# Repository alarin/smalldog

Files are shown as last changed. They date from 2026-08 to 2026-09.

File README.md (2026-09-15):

# SmallDog

A 12-DOF printed quadruped ("mini robot dog") built around 12 × Feetech/Waveshare
**ST3215** bus servos — parametric CAD, FEA, a ROS 2 / MuJoCo simulation, an RL policy and
the hardware runtime, all of one robot.

| | |
|---|---|
| [`3d/`](3d/) | **the source of truth.** Pure code-CAD (CadQuery): every dimension, mass and joint limit lives in [`3d/mini_dog.py`](3d/mini_dog.py). Also linear-static FEA ([`fea.py`](3d/fea.py)) and the URDF/MJCF exporter ([`export_sim.py`](3d/export_sim.py)). |
| [`ros2/`](ros2/) | ROS 2 workspace: generated description, `ros2_control` wiring, trot gait, teleop, SLAM + Nav2 + room exploration, MuJoCo standing in for the hardware. |
| [`rl/`](rl/) | the RL walking policy: MJX/Brax PPO against the same generated model. |
| [`robot/`](robot/) | the hardware side: ST3215 bus driver, the identification bench, the 50 Hz runtime. |

Everything structural is FDM-printed (PETG/ASA): no aluminium, no machining, no external
bearings — only the stock servos and their aluminium hubs.

## One model, three consumers

`ros2/smalldog_description` is **generated**, not authored:

```bash
cd ros2 && ../3d/.venv/bin/python smalldog_description/scripts/generate_model.py
```

Masses, inertias, link lengths, joint limits, the actuator constants and the sensor
parameters are all read out of `3d/mini_dog.py`. A number that is wrong in simulation is
wrong in the CAD — fix it there and re-export. [`3d/CLAUDE.md`](3d/CLAUDE.md) has the
change workflow (rebuild → FEA → re-export sim → regenerate the ROS 2 description).

## Machines

| machine | does | runbook |
|---|---|---|
| a mac | CAD, FEA, both sim exporters, the ROS 2 workspace | [`3d/CLAUDE.md`](3d/CLAUDE.md) |
| Windows/WSL2, RTX 3070 | RL training, the pure-Python sim regressions | [`WSL.md`](WSL.md) |
| Windows/WSL2, RTX 5070 Ti | RL training with the procedural boxes at full batch | [`GPU.md`](GPU.md) |
| Orange Pi 5 Pro | the runtime on the robot | [`robot/README.md`](robot/README.md) |

No shared filesystem between them: the git repository is the only thing that crosses.

## Where to read

- Printed parts, servo interface, assembly: [`3d/README.md`](3d/README.md)
- Simulation, gait, teleop, SLAM and navigation, regressions: [`ros2/README.md`](ros2/README.md)
- Bench, bring-up, the measured servo: [`robot/README.md`](robot/README.md) and the public
  reference [`ST3215_STS3215_measured_parameters.md`](ST3215_STS3215_measured_parameters.md)
- Power tree and its **verify** list: [`POWER.md`](POWER.md)
- What to build next: [`PLAN.md`](PLAN.md)

## Not in this repository

Generated output is ignored — `3d/out/` (STEP/STL/BOM/renders/FEA meshes), `rl/runs/`
(checkpoints) and the colcon `build/`, `install/`, `log/` trees. Re-run the scripts to
produce them.

`3d/ref/` holds vendor downloads (ST3215 STEP + drawings, Waveshare ROBOTIC DOG STEP) and
transcribed measurements of bought parts, used as inputs only; they remain the property of
their respective vendors.

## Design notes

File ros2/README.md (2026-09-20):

# SmallDog — ROS 2 + MuJoCo

12-DOF quadruped simulation for the printed ST3215 dog designed in [`../3d`](../3d):
description → ros2_control → gait node, with MuJoCo standing in for the hardware.

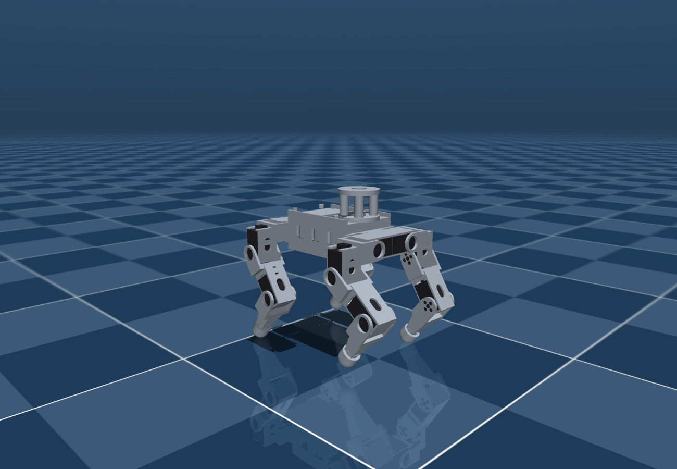
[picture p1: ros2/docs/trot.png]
trot


## Packages

| Package | Type | Purpose |
|---|---|---|
| `smalldog_description` | ament_cmake | URDF, link meshes, MuJoCo model — **all generated from the CAD** |
| `smalldog_ros_control` | ament_cmake | ros2_control wiring + MuJoCo launch |
| `smalldog_walker` | ament_python | trot gait + analytic leg IK, `/cmd_vel` → joint trajectory |
| `smalldog_teleop` | ament_python | keyboard teleop |
| `smalldog_hardware` | ament_python | **the real robot**: `robot/runtime`'s servo loop behind the walker's topics, the L2 and the camera as topics, `/diagnostics` and a Foxglove bridge — "On the robot" below |
| `smalldog_nav` | ament_python | SLAM + Nav2 + the frontier explorer: the robot maps a room by itself — "SLAM and navigation" below |
| `tools/` | — | standalone MuJoCo sim, no ROS needed |

One external source dependency: **`mujoco_ros2_control`**, a fork on its `kilted` branch,
vendored as a submodule at `src/mujoco_ros2_control`. The LiDAR publisher, the camera
checks and the real-time pacing live there, so a pull that touches them needs one
`colcon build --packages-select mujoco_ros2_control`.

## Build & run

The workspace has its own ROS 2 environment in `pixi/` (macOS arm64 only, as committed).

```bash
pixi install --manifest-path ros2/pixi/pixi.toml    # ~2.3 GB, once
git submodule update --init                        # src/mujoco_ros2_control
source tools/env.sh
colcon build --symlink-install
```

Four pins in `pixi/pixi.toml` are load-bearing: `ros2_control 5.6` / `ros2_controllers 5.7`
(by hardware_interface 5.12 the fork's `MujocoSystemInterface` matches no `import_component`
overload); `libmujoco 3.3` (`mjv_moveCamera` grew an argument after); `clang_osx-arm64` by
name (without the conda wrapper's `-dead_strip_dylibs` the node links 18 rosidl dylibs it
never calls and dies at startup on `_PyExc_RuntimeError`); and `filelock`, which the
controller spawner imports.

One controller parameter is load-bearing too: `interpolate_from_desired_state: true` on
the trajectory controller (`config/smalldog-controllers.yaml`). ros2_controllers 5.7
renamed `open_loop_control` to it and dropped the old key without a word, and with it off
every streamed point restarts the interpolation from where the lagging servo actually is:
the trot reached the joints at ~40 % of its amplitude, and a 0.5 rad/s turn came out at
0.026 rad/s against 0.30 in the standalone sim (0.27 with the key). The walker also
clocks the gait on measured elapsed time now, not the timer's nominal period — a loaded
mac fires its 100 Hz timer at 65.

### Run

One terminal. Keys are read by the **MuJoCo render window** — the sim node republishes
every printable key on `~/key`, and the teleop node turns them into `/cmd_vel`. Click the
window and type.

```bash
./tools/sim.sh                 # flat ground, real time
./tools/sim.sh terrain:=true   # the heightfield scene
./tools/sim.sh teleop:=false   # no teleop node — drive it from a second terminal
./tools/sim.sh foxglove:=true  # plus a Foxglove websocket on ws://localhost:8765
./tools/sim.sh rtf:=2.0        # twice real time; rtf:=0 is unpaced (long unattended runs)
```

`sim.sh` kills stray `robot_state_publisher` processes first: a leftover keeps the next
`controller_manager` from coming up (`waiting for service /controller_manager/list_controllers`
forever). `tools/teleop.sh` is the second-terminal path for a headless or remote run; launch
with `teleop:=false` when you use it, or two teleop nodes fight over `/cmd_vel`.

```bash
pkill -f "ros2 launch smalldog"; pkill -f robot_state_publisher    # stopping
```

`tools/env.sh` picks `local_setup.zsh` or `.bash` to match the shell: sourcing the `.bash`
file from zsh silently never applies the overlay (`$BASH_SOURCE` is unset), and
`ros2 run smalldog_teleop keyboard` then says "package not found".

By hand:

```bash
eval "$(pixi shell-hook --manifest-path pixi/pixi.toml)"
source install/local_setup.bash
ros2 launch smalldog_ros_control smalldog-mujoco.launch.py
ros2 run smalldog_teleop keyboard                            # second terminal
```

### Checking it is alive

```bash
ros2 control list_controllers        # both must say "active"
ros2 node list | grep smalldog       # walker, controller, keyboard_teleop
ros2 topic info /cmd_vel             # 1 publisher (teleop), 1 subscriber (walker)
ros2 topic echo /mujoco_ros2_control_node/key   # what the render window is seeing
```

If the legs do not move: the teleop prints the `vx / vy / wz` it sends on every key. Silent
key topic → the MuJoCo window has no focus. Keys but no `/cmd_vel` → the teleop node is not
up. `/cmd_vel` with **2 publishers** → a leftover teleop still holding a command.

## Keyboard

```
  w / s      walk forward / back
  a / d      strafe left / right
  q / e      turn left / right
  space      stop
  r / f      body up / down          (0.09 … 0.20 m)
  , / .      speed  -  / +           (0.05 … 0.45 m/s)
  t          gait enable / disable
```

Published: `/cmd_vel` (Twist), `/smalldog/body_height` (Float64), `/smalldog/enable` (Bool).
Subscribed: `/mujoco_ros2_control_node/key` (String, one character per press). Backspace
belongs to the viewer and resets the sim. `read_stdin:=false` turns the raw-TTY reader off;
the node does that by itself whenever stdin is not a TTY.

## Without ROS 2

The gait and IK have no ROS imports, so everything runs from a bare env with `mujoco` and
`numpy`:

```bash
./tools/view.sh                             # interactive viewer, same key bindings
./tools/view.sh --terrain --lidar           # rough ground, with the LiDAR cloud drawn
python tools/standalone_sim.py --headless   # self-test: stand, trot, turn
python tools/standalone_sim.py --terrain    # either mode, on the rough-ground scene
python tools/standalone_sim.py --course     # 25 s over the ramp/wall/log obstacle course
python tools/standalone_sim.py --lidar      # ... with the L2 scanning (needs ../3d beside)
```

The interactive viewer goes through `tools/view.sh`: on macOS the passive viewer needs
`mjpython`, which cannot dlopen the uv venv's interpreter, and the wrapper sets
`DYLD_FALLBACK_LIBRARY_PATH` from `sysconfig`.

**Both viewers are paced to real time** (measured 1.000× off `/clock`; `rtf:=` on the ROS
launch, `CATCHUP` in `interactive()`). Unpaced they ran 1.5–3× real time, which is exactly
the kind of thing you calibrate your eye against. A machine that cannot keep up degrades
to slow motion rather than sprinting through a backlog. The headless runs are deliberately
not paced. Rendering is ~70 % of a frame and physics plus the whole ros2_control stack 7 %;
nothing there is worth optimising.

Current self-test:

```
model ok: 18 dof, 12 actuators, mass 2.493 kg
  stand    z= 170.6 mm  roll= +0.0 pitch= +0.1
  hold 1s  z= 170.5 mm  roll= +0.0 pitch= +0.0  drift= 21.0 mm
  trot 5s  z= 169.9 mm  roll= +2.8 pitch= -1.1  travelled x= 457.9 mm  y= -10.6 mm
  turn 4s  z= 152.9 mm  roll= +1.5 pitch= +1.4
RESULT: OK — stands and trots forward
```

`settle()` seeds the gait's rate limiter from the stance (it used to take one command at
`dt = 0`, which the limiter turned into 3e-4 rad, so the robot "settled" with straight legs
and every trot started from a ramp). The flat trot is deterministic to 0.1 mm and is the
control for any change; the terrain and course arms are read over seeds. `3d/CLAUDE.md`
carries the current baseline and how to read it.

## Rough ground

`mujoco/scene_terrain.xml` is the same world with the plane swapped for a heightfield —
`meshes/terrain.png`, generated by `../3d/terrain.py` and rewritten by `generate_model.py`.
Seeded fractal noise, ±27 mm over 160 mm (36° peak slope), flat inside 160 mm of the origin.
Same seed, same ground.

```bash
python tools/standalone_sim.py --headless --terrain            # default seed
python tools/standalone_sim.py --headless --terrain --blind    # feedback off
```

**One seed is not a measurement.** At fixed settings the trot spreads ±70 mm across seeds
and one seed moves ±100 mm under mass changes far too small to be a geometry regression.
Sweep seeds 7…12, one png per seed — MuJoCo caches a heightfield by file name inside a
process, so rewriting `terrain.png` and reloading silently reuses the first field compiled.
A dead-flat heightfield already costs the blind gait ~15 % against `type="plane"` (that is
the hfield contact, not the relief), so raising the amplitude is not the knob it looks like.

Terrain feedback against `--blind`, twelve seeds: better on 10 of 12; the blind trot rolls
over on two seeds and the closed loop never exceeds 13° of tilt. It costs ~4 % on the flat.

### The obstacle course

The heightfield alone is smooth — a foot always lands on a hillside. The scene also
carries ramps, walls and logs (`COURSE` in `../3d/terrain.py`) along +x, graded to what the
trot can clear (measured one obstacle at a time: ramps to 14°, walls to ~18 mm, logs to
~22 mm — the wall cliff between 18 and 22 mm is the 22 mm foot swing exactly). It starts at
x = 0.95 m, past what the 5 s regression trot reaches, so `--headless --terrain` measures
the relief and nothing else. `--course` walks it:

```
course: log at 950, ramp_up at 1583, deck at 1875, ramp_dn at 2166, wall at 2600, ...
  cleared 2/7: log ramp_up
  furthest x while inside the course corridor: 1791 mm
RESULT: upright ...
```

An obstacle is credited only when the robot passed it while still inside the 0.80 m
corridor — scoring on x alone credits walking around things. It is a *report*, not a
pass/fail: the unchanged model reads 5/7, 4/7 and 3/7 across sessions on one seed, and
seed 7 sits on a knife edge at the first obstacle. Read it over seeds 7 / 8 / 9.

An obstacle's rotation is a **quaternion**: `robot.xml` compiles with `angle="radian"`, so
a degree value is read as radians without a word. Ray-cast the *compiled* scene to check.
`generate_model.py --no-terrain-obstacles` leaves the course out;
`--terrain-amp/--terrain-wave/--terrain-seed` regenerate the field (restart the sim — it
keeps the heightfield it loaded).

### Terrain feedback

`smalldog_walker/gait.py` closes three loops on top of the open-loop profile, all fed by
`TrotGait.feedback(quat=..., gyro=..., contact=...)`:

- **body levelling** on the IMU: a body rotation lifts the foot corner at (x, y) by
  `roll·y − pitch·x` and the leg retracts by the same amount. Acts on the attitude
  low-passed over 0.30 s — most of what the IMU sees is the trot's own rocking, and chasing
  that costs half the forward speed.
- **stand where you land**: a debounced contact partway through the swing means the ground
  came up; the foot stops there instead of finishing a sine that would peel it off.
- **heading hold** on the IMU yaw. The command is in body axes, so a robot knocked off
  course curves through the world and the profile cannot notice. The reference is latched
  when it last started walking straight and dropped on a commanded turn.

Hold off → on over six terrain seeds: on the flat nothing changes; on the relief the final
|yaw| goes 9.4° → 3.9°; on the course 46.6° → 10.3°, path 2292 → 2836 mm, 1/6 → 0/6 down,
and the default seed goes from 1 obstacle cleared to 5. The loop corrects heading, not
position. **Sim yaw is truth; hardware yaw is an integrated gyro** (no magnetometer) — it
holds a line over a run, not an absolute bearing.

All three are optional and additive: with neither stream arriving, or either stale for
0.20 s, the gait is the blind gait. Under the ROS 2 launch the IMU arrives
(`imu_sensor_broadcaster`; the walker logs `IMU is live`); the foot contacts have no
publisher (Known gaps). Contact thresholds are keyed to the *measured* phase lag — the foot
leaves at s ≈ 0.6 and lands at ≈ 0.05, a tenth of a cycle behind the profile — and that lag
is the gait's own rate limiter, not the servo, so it wants re-measuring on hardware.

## LiDAR

The Unitree L2 is in the model as a **sensor**: `mujoco/robot.xml` carries a `lidar` site at
its optical centre and a `<custom>` block with the scan parameters, both written by
`../3d/lidar.py` out of the CAD.

```
/mujoco_ros2_control_node/lidar/points   sensor_msgs/PointCloud2, 12 Hz, SensorDataQoS
```

~5195 points a frame (measured 62340 /s at 12 Hz), float32 xyz in `lidar_link`, whose +Z is
the sensor's own axis, pointing forward (`LIDAR_TILT` 90). Simulated time stamps. About a quarter of the
rays return: the ground from ~280 mm ahead outwards, the course, and the robot's own legs
(the chassis it is bolted to is excluded; the legs are not, because a real sensor sees
them). The publisher is `src/mujoco_ros2_control/.../mujoco_lidar.{hpp,cpp}`; it uses
`mj_multiRay` with no GL context, runs at the sim cadence, and stays quiet on a model with no
`lidar` site. The scan *pattern* (measured, `3d/ref/lidar/`) exists twice — Python and C++ — because neither can
call the other; the parameters exist once, in the CAD. `smalldog_nav` is what subscribes
to the cloud.

**GPS**: mass and a frame only — 25 g on the mast, a `gps` site at the patch's phase centre
and a `gps_link` on TF (+Z the patch normal). No simulated fix; on hardware it is an NMEA
stream on a UART, not a ROS 2 sensor this workspace owns.

### Looking at it

```bash
./tools/view.sh --terrain --lidar              # MuJoCo's own viewer, cloud drawn into the scene
./tools/sim.sh terrain:=true foxglove:=true    # ROS 2 topic → ws://localhost:8765
```

The viewer draws the last six frames (0.6 s) in world coordinates, coloured by height,
subsampled to `CLOUD_MAX` = 6000 spheres. For the ROS 2 topic use **Foxglove, not RViz**
(`rviz2` is not in the pixi env and is not going in): *Open connection* → *Foxglove
WebSocket* → `ws://localhost:8765`, a 3D panel, the `…/lidar/points` topic, frame
`base_link`. The bridge advertises `/tf`, `/tf_static` and `/robot_description` with the
`assets` capability, so the URDF and its meshes load. It binds `127.0.0.1`; change `address`
in the launch file to watch from another machine. QoS matches the publisher's automatically.
The MuJoCo window the ROS launch opens does **not** show the cloud.

```bash
ros2 topic hz /mujoco_ros2_control_node/lidar/points
ros2 bag record -s mcap /mujoco_ros2_control_node/lidar/points /tf /tf_static /clock
```

Foxglove opens an `.mcap` directly, which is how to look at a run from another machine.

## SLAM and navigation

`smalldog_nav` maps a room with the L2 and walks it by itself. One command in the sim:

```bash
./tools/explore.sh                          # MuJoCo in the walled room + SLAM + Nav2 + explorer
./tools/explore.sh rtf:=2.0 save_map:=/tmp/room
```

Watch it on Foxglove (`ws://localhost:8765`, a 3D panel, frame `map`): `/map`, `/scan`,
`/global_costmap/costmap`, `/plan`. The MuJoCo window shows the robot; keys typed over it
do nothing here (`teleop:=false`, Nav2 owns `/cmd_vel`).

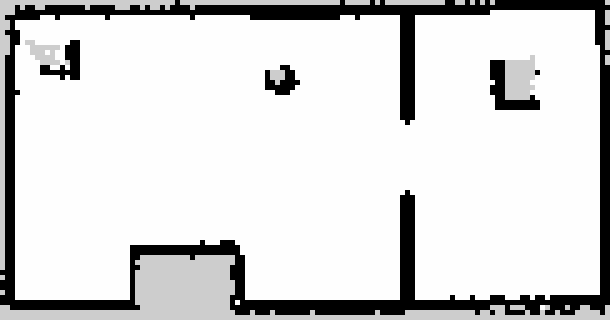
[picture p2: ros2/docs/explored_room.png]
the room, explored


What one run reads (2026-09-15, real time, the mac in a video call beside it): a 25 s spin
on the spot, then ten goals in 4.5 min, one blacklisted, and `explored: no frontier left.
17.8 m2 known, 15.2 m2 free` — the two rooms are 18 m² of floor. The map above is that
run's `save_map` output: both rooms, the doorway, the pillar, the couch and both crates,
walls one cell thick. Most goals end as "is mapped, moving on" rather than "reached": a
frontier is the edge of what the L2 has seen, and on a 6 m sensor in a 6 m world the edge
moves before the robot gets there — that is the exploration working, not failing.

The chain, each step one node:

| step | node | in → out |
|---|---|---|
| odometry | `smalldog_walker` (in the walker, `odom:=true` default) | gait velocity + IMU yaw → `/odom`, TF `odom → base_footprint → base_link` |
| cloud → scan | `smalldog_nav cloud_to_scan` | the L2 cloud → `/scan`, a 0.10..0.35 m slice in the level frame, ±96°, plus every drop in the floor as a wall at its edge |
| SLAM | `slam_toolbox` (async, mapping) | `/scan` + `odom` → `/map`, TF `map → odom` |
| navigation | Nav2: planner (NavFn), controller (regulated pure pursuit), behaviors, BT | `/map`, `/scan`, a goal → `/cmd_vel` |
| exploration | `smalldog_nav explore` | `/map` → `navigate_to_pose` goals until no frontier is left |

`nav.launch.py` is the chain without the sim, for either machine:

```bash
ros2 launch smalldog_nav nav.launch.py explore:=true                 # sim (sim.sh teleop:=false first)
ros2 launch smalldog_nav nav.launch.py use_sim_time:=false cloud:=/lidar/points speed:=0.12 explore:=true
                                                                     # robot (robot.launch.py imu:=true lidar:=true)
ros2 topic pub -1 /smalldog/explore std_msgs/msg/Bool "{data: false}"   # pause; true resumes
```

**With the gamepad** the two take turns on `/cmd_vel` instead of fighting: launch with
`explore:=true autostart:=false`, and **Back** hands the robot to Nav2 (the pad goes
silent — no zeros either); any stick push or B takes it back and pauses the explorer;
Back again resumes. When the explorer finishes it hands the pad back on its own.

**Odometry** is dead reckoning: the walker integrates the velocity its stance feet are
sweeping (the command after the heading hold and the stride clamps, `TrotGait.body_velocity()`)
times `odom_scale`, and takes heading from the IMU (truth in the sim, an integrated gyro on the
robot). `odom_scale` is the foot slip: the sim trot delivers ~0.5 of its command on the flat
(measured against `qpos` over 6 s: 0.53 at 0.15 m/s, 0.49 at 0.10, 0.67 at period 1.35), so
the sim launch sets 0.5; the robot's is unmeasured (**verify** — walk a taped 2 m and compare
`/odom`). slam_toolbox's scan matcher absorbs the rest; a scan node every 0.1 m keeps its
0.5 m search window honest. `base_footprint` is the level frame: base_link lifted by the
standing height and tilted back by the IMU's roll and pitch, so the scan slice keeps the
floor out while the trot rocks the body ±3°.

**The scan** is ±96° — the L2's cone about its forward axis — and no wider: behind the
robot is unknown, not clear (an empty bin is `inf`, dropped by both consumers), which is
why the explorer spins once before choosing a goal. `cloud_to_scan` is this package's own
sixty lines rather than `pointcloud_to_laserscan`: that node's TF message filter held every
cloud and dropped it ten seconds later under this Kilted env while `can_transform` said yes
throughout (the header of `cloud_to_scan.py` has the details).

**A drop is a wall.** The slice cannot see a stairwell — empty air in the band is free
space — and the explorer walked the robot down one (2026-09-16, two legs). The L2 looks
down as well as out, so `cloud_to_scan` takes every return more than `drop_depth`
(0.12 m) below the floor plane within `drop_range` (2 m) and puts it in the scan at the
range where its ray crossed the floor — the edge, not the tread. Measured held at the
landing: the edge reads 0.44–0.6 m at half a metre, and the stairwell is a wall in both
the map and the costmap. `drop_depth` is a tilt tolerance too: 3.4° of level-frame
error at 2 m, 7° at 1 m, so the IMU has to be up (`imu:=true`) for it to be honest.

**The explorer** takes free cells with an unknown neighbour, clusters them, and walks to
the cluster that scores best on distance minus half its length — a long edge across the
room beats a fragment beside the robot. A goal is a cluster cell with no obstacle within
0.28 m, so the planner never has to reject one; a goal that stops being a frontier is
dropped, not walked out; a goal Nav2 fails is blacklisted (0.4 m). No frontier three checks
running → done: it prints the known and free area, saves the map (`save_map:=stem` →
`stem.pgm` + `.yaml` through `/slam_toolbox/save_map`) and walks back to the origin.

**Nav2's numbers that are this robot's** (`config/nav2.yaml`): `robot_radius` 0.18, inflation
0.35, no reversing, rotate-to-heading on, 0.5 rad/s turns (the gait's own clamp), no lateral
commands, `Twist` not `TwistStamped` (`enable_stamped_cmd_vel: false`, the walker reads
`Twist`). The straight-line speed is the launch's `speed` (0.15 in the sim; 0.08 on the
robot with the heading hold, robot.launch.py). slam_toolbox is a lifecycle node in Kilted
and comes up unconfigured — its own `lifecycle_manager_slam` brings it up, before Nav2's
manager, whose planner waits for the `map` frame at activation.

Two things bit on the way in and are worth knowing: the pixi env for this came in with a
truncated `libspqr.4.dylib` (a dropped download; slam_toolbox died at configure with
"mutex lock failed") — sizes against `conda-meta/*.json` find such a file, delete it and its
rattler cache dir and `pixi install` again; and the IMU spawner's default 10 s service
timeout gave up under this launch's load, so the sim launch now passes
`--service-call-timeout 30`.

The room, `mujoco/scene_room.xml` (`room:=true` on the sim launch; `ROOM` in
`generate_model.py`): 4 × 3 m with the robot at the centre facing +x, a 0.8 m doorway into
a 2 × 3 m second room, a pillar, a couch and two crates, walls 0.5 m tall.

### The other frontend, and why nothing is built on it

`robot/slam/slam.py` is a second, unrelated answer to the same problem: KISS-ICP on the
full 3-D cloud instead of slam_toolbox on a 2-D slice, with no odometry input at all.
`tools/walk_map.py` measures it, in this same room:

```bash
python tools/walk_map.py --selftest      # the harness, 4 s
python tools/walk_map.py --path patrol   # both rooms and the doorway, scored against truth
python tools/walk_map.py --path still    # the control arm
```

It trots the gait through `scene_room.xml`, casts the measured L2 pattern **with motion
distortion modelled** (`lidar.Scanner` casts a whole frame from its end pose; this casts
it in `--slice-ms` pieces as the robot moves, which is what a sweeping sensor really hands
you), feeds that odometry, and scores both the trajectory and the map against MuJoCo's own
truth. `--rigid` is the no-smear control, `--stack N` registers N frames at once. It keeps
no description of the room: the surfaces come out of the compiled model, so it scores
against the scene that was actually simulated and cannot drift from it.

**The 3-D frontend does not hold a pose** — 0.48 m of drift with the robot standing
perfectly still, replaying the real onboard capture, because one 83 ms L2 frame is 18
meridian sweeps rather than a sample of the surfaces. That is the measurement behind
`smalldog_nav` taking the 2-D-scan-plus-gait-odometry route, and the reason to keep taking
it. The numbers, the cause and what would change it are in
[`../robot/README.md`](../robot/README.md), "SLAM".

## Regenerating the model from CAD

```bash
../3d/.venv/bin/python smalldog_description/scripts/generate_model.py
```

Imports `../3d/mini_dog.py`, exports one STL per link in its own frame, integrates mass
properties from the tessellated solids at measured print density plus the payload point
masses, and writes `urdf/smalldog.urdf`, `mujoco/{robot,scene,scene_terrain,defaults}.xml`,
`meshes/terrain.png` and `robot_params.json`. **Every density, mass, limit and actuator
constant comes from `mini_dog.py`** — this script keeps no copies (it did, and the servo
mass, the joint limits and the `MJ_*` constants each drifted once). The workspace is built
`--symlink-install`, so regenerated files are picked up without a rebuild; a *new* file
needs one `colcon build --packages-select smalldog_description`.

`../3d/export_sim.py` is the other exporter of the same CAD (different link decomposition:
the foot is a separate part there). Both are re-run after a model change; `3d/CLAUDE.md`
step 6 is the checklist.

`robot_params.json` is the single source the gait, the runtime and `rl/` read: link
lengths, hip offsets, the three limit ladders, the rate ceiling, the nominal stance.

## Model facts

| | |
|---|---|
| total mass | 2.493 kg (base 1.559 kg incl. battery, Orange Pi, LiDAR, GPS, camera, IMU) |
| leg reach | 98…152 mm from the hip-pitch axis → usable body height 150…170 mm |
| joints | `{fl,fr,rl,rr}_{roll,pitch,knee}` — 12 servo IDs 1…12 in that order |
| joint limits | roll ±1.5708, pitch ±1.5708, knee ±1.9199 rad — **read** from the CAD ROM scan (`3d/out/bom.json`) via `export_sim.joint_rom()`, so the two exporters cannot drift |
| MuJoCo hard stops | 0.03 rad **inside** the URDF limits, so the measured position can never trip ros2_control's joint limiter |
| gait soft limits | 0.12 rad inside the mechanical limits → roll/pitch 1.4508, knee 1.7999 |
| joint effort / velocity | 3.2 N·m, the torque rig's full-duty peak (PLAN.md 3d; the held 2.3 is a runtime budget); 3.28 rad/s achievable ceiling `(forcerange − frictionloss)/damping`, below the measured 3.86 no-load; the generator takes `min()` |
| nominal stance | base 181 mm above ground, gait default 158 mm |
| meshes | 13 link meshes + 12 ST3215 bodies (visual only — their mass is in each link's `<inertial>`) |
| links | `base_link` + `{leg}_hip` / `{leg}_thigh` / `{leg}_shin` (foot fused into shin), plus fixed `imu_link`, `lidar_link`, `gps_link` |

`robot_params.json` keeps **one magnitude per kind** in `joint_limits_rad` and
`joint_soft_limits_rad`, because every consumer reads it that way; the signed per-leg pairs
are in `joint_limits_rad_signed`, and the generator asserts the scan is symmetric before
writing them. ±90° of roll and pitch is where the ROM *scan window* stopped, not where the
leg fouls; widening the scan in `3d/mini_dog.py` is the way to find out. The soft limits
also clamp the real servos (`robot/runtime/calib.py`).

Collision model: boxes/capsules for the links, a sphere per foot with its own friction and
`priority="1"`, `condim="4"` (`3d/CLAUDE.md` has why). Self-collision is off — joint limits
already come from the CAD sweep. `sum(model.body_mass)` matches `robot_params.json` exactly.

## Gait

`smalldog_walker/gait.py` — trot, diagonal pairs `(FL,RR)` / `(FR,RL)`, duty 0.5.

- `period` 0.45 s, `swing_height` 22 mm, `max_step` ±60 mm fore/aft, ±30 mm lateral
- **the leg is short**: 75 + 82 mm gives ~50 mm of vertical foot travel, so `body_height`
  is clamped to the band where stance and swing apex both stay in reach; asking for more
  shrinks the swing instead of producing an unreachable target
- yaw folds in as `v + ω × r_hip`; a `_moving` blend keeps the feet planted when the command
  drops to zero
- joint outputs are clamped to the soft limits, then rate-limited against
  `joint_rate_ceiling_rad_s` = 3.28 from `robot_params.json` (the achievable joint speed
  under load; it used to limit against the vendor no-load speed and 32 % of commanded
  samples asked for a speed the joint does not have)

`leg_kinematics.py` is closed-form: the roll angle comes from the requirement that the foot
lands in the thigh/shin plane, then a 2-link solve in that plane. FK/IK round-trip to 1e-6:

```bash
PYTEST_DISABLE_PLUGIN_AUTOLOAD=1 python -m pytest smalldog_walker/test -q   # 11 passed
```

(the prefix is not optional in this pixi env — `launch_testing` registers a pytest hook
against an older pluggy and pytest refuses to start).

### Forward speed, and what does not move it

The trot achieves ~75 % of the commanded speed. Four hypotheses were measured and are dead:
not torque (force inside ±3 N·m 99 % of every run), not actuator stiffness (`kp` 25 → 200
cuts tracking error 3× and moves the distance not at all), not the swing profile (a C1
profile that halves peak knee demand is a regression), not rate-limit clipping (a period
long enough to satisfy the limiter is inside one seed-sweep's noise). What explains it:
**the body advances mostly by the foot moving over the ground, not by the stance sweeping**
— stretch the period and the loaded stroke falls while ground travel rises, and the sum is
unchanged. The operating point is a traction equilibrium set by the foot friction and the
sphere-on-heightfield contact, and tuning those would make the simulation faster without
making the robot faster. The answer is in the real foot on the real floor (PLAN.md step 5).

### The foot's contact patch, and why growing it changed nothing

The foot is one `sphere` geom, so one contact point at any attitude; the shin is 34.6° off
vertical while carrying load (46.7° worst), so the dome touches a third of the way round its
side and rolls ~25° during a stance. `tools/foot_contact.py` builds alternatives through
`MjSpec` (writing nothing) and runs each beside the unchanged control:

| arm | what it is | flat, mm | rough, mm (6 seeds) | pts/foot | skid |
|---|---|---|---|---|---|
| `base` | as shipped — **the control** | 781.1 | 625.6 ±94 | 1.00 | 28.7 |
| `grip` | same dome, torsion friction on | 785.5 | 572.1 ±222 | 1.00 | 32.5 |
| `pad` | dome truncated 3.5 mm to a ⌀17.7 flat, raked to the loaded shin | 773.6 | 531.8 ±176 | 1.37 | 25.1 |
| `tripod` | three ⌀10 lobes on a ⌀16 ring | 760.4 | 485.1 ±252 | 1.88 | 30.9 |
| `ankle` | flat pad on a passive sprung rocker | 445.8 | 404.7 ±117 | 1.33 | 199.9 |

(Measured before the fitted actuator, so the absolute distances are old; the comparison
holds.) A real patch buys nothing: flat within ±21 mm of the control, rough equal or worse
against the seed spread, the passive ankle unambiguously negative at every spring rate.
`--push` says why: lean 6 N on the standing robot and the body gives 5.6 mm whatever the
foot is — the compliance that matters is the servo's `kp`, and Coulomb friction does not
depend on area. MuJoCo contact is rigid; what a TPU dome does under 60 N (squash into a
patch) is not represented at any shape.

What *was* changed is the contact model in `3d/mini_dog.py` section 4 (`MJ_FOOT_*`, read by
both exporters): `condim` 3 → 4 so a planted foot resists twist (not 6 — rolling triples the
terrain spread), a torsion coefficient derived from the real patch (⅔·a·μ·f_n, a =
1.4…2.1 mm in 95A TPU), and `priority="1"` so the foot's numbers — `solref`/`solimp`
included — win over the floor's. Check a contact model by reading `d.contact[i].friction`.

Two harness facts before repeating any of this: **the heightfield cannot compare feet** —
at `CELL_MM` = 12 a ⌀17.7 face is smaller than one cell and collides with prism walls
(`tripod` stood still with 4 kN through its touch sensors); `--rough` (a plane strewn with
tilted slabs) is the arm that can. And the walker feeds on `<touch>` sites of r = 14 mm
around each ankle; a foot whose contacts land further out is a foot the walker cannot feel
(`SITE_R`, and the `site` control arm that proves the enlarged site is inert on its own).

## On the robot

The Orange Pi runs Ubuntu 24.04 with ROS 2 Jazzy from apt (`/opt/ros/jazzy`, no pixi, no
ros2_control). `smalldog_hardware/servo_node.py` is the hardware side: it wraps
`robot/runtime` — the bus driver, `calib.json`, the safety guard, the 50 Hz tick — and
subscribes to the same `/smalldog_controller/joint_trajectory` the walker streams to the
MuJoCo controller, so the walker does not know which one it is driving. It publishes
`/joint_states` (effort = Present Load) and, with `imu:=true`, `/imu` from the BMI088.
There is no ros2_control plugin on purpose: the runtime is the one copy of the servo
handling the bench can test, and a C++ hardware_interface would be a second.

```bash
cd ~/smalldog/ros2 && source /opt/ros/jazzy/setup.bash
colcon build --symlink-install --packages-select smalldog_description smalldog_walker smalldog_teleop smalldog_hardware
source install/setup.bash
ros2 launch smalldog_hardware robot.launch.py imu:=true joy:=true   # stand; drive it from the gamepad
ros2 launch smalldog_hardware robot.launch.py mode2:=false ...        # the servo firmware's own loop (the old runtime)
ros2 launch smalldog_hardware robot.launch.py imu:=true lidar:=true  # + the L2 on /lidar/points, for smalldog_nav
ros2 run smalldog_teleop keyboard --ros-args -p speed:=0.12 -p turn:=0.9   # or a keyboard, second terminal (MODE 2 fit)
tools/robot_go.sh 5 0.08                                   # or: walk straight 5 s, hands off
ros2 launch smalldog_hardware robot.launch.py policy:=rl/policy lidar:=true   # the RL policy as the walker
```

`policy:=<dir>` replaces the IK trot with the RL policy (`rl/policy/`): the servo node runs
`runtime.policy.PolicySource` itself at 50 Hz, takes `/cmd_vel` (vx 0..0.4, vy ±0.1,
wz ±0.5, zero after 0.5 s, slewed at 0.4 m/s² and 1 rad/s² because the policy rears on a
stepped command), publishes `/odom` and the TF pair like the walker, and stands up
fold → stance before handing over (servo_node.py, "The RL walker"). The trot slid in place
on the glossy laminate at any speed (2026-09-17); the policy walks it at ~0.18 m/s at cmd 0.2.

**Every run is recorded** unless `log:=''`: the servo node writes each tick (feedback, goal,
duty, IMU, command) into `~/smalldog_logs/tick_<stamp>.npz` on the Pi, a ring of the last
30 min written on exit and on a trip (`robot/runtime/ticklog.py`; the same format as
`walk.py --log`). `python3 robot/bench/incident.py FILE` reads it back: how the run ended,
each joint's peak duty, current and error with the time, the body's peaks, the last seconds
tick by tick. Copy the file to the mac and commit it under `robot/bench/data/` if it is worth
keeping — the run that broke the front hip brackets left nothing.

Three launch arguments exist because of that run (2026-09-17, `robot/README.md`
"The guard"):

- `reverse:=true` admits vx down to −0.2. Off by default: Nav2 never asks the RL walker to
  reverse except through the BackUp recovery, and the shipped stage 2 policy reverses
  nose-down until it trips on the front legs (`ideas/TRAIN_HOST_LOOP.md`).
- `tilt_deg:=` is the guard's roll-or-pitch trip: 25 with a policy (its own pitch is under
  5°; the hops peaked at +32 and the trot's 40 let them land), 40 for the trot. **verify**.
- `duty_cap:=pitch=600` caps the hip pitch servos at the ~2.3 N·m the firmware's own
  protection allowed in position mode (`robot/runtime/mode2.py`, "A torque ceiling").
  Slower joints; the exit report prints the peak each capped joint reached. **verify**.

The heading hold no longer re-latches its reference while the body is still turning after
a Nav2 turn (it waits for the yaw rate to settle, then holds the heading the robot
actually stopped on), and its own wz is slewed at the same 1 rad/s²
(`runtime/policy.py`, `HeadingHold`; `python3 runtime/policy.py --selftest` without a
policy dir runs that check alone).

`mode2:=true` (the default since 2026-09-16) runs the servos in MODE 2 with the position
loop on the Pi — `robot/runtime/mode2.py`, `ideas/FAST_SERVOS.md` — and hands the walker
`joint_rate_ceiling` 4.7 rad/s, so `fit_cmd`'s budget goes straight to 0.164 m/s
(dry run) instead of 0.11. The launch's `speed` default, `PERIOD` and `odom_scale` were
measured under the firmware's loop and still hold as a conservative operating point; the
bench walk at 0.16 m/s / 0.95 s slipped to ~0.10 real on the bare bench (**verify** on the
floor with `tools/straight_test.py` before raising `speed`).

`voice:=true` is `smalldog_hardware/ears_node.py`: the camera module's mic through
sherpa-onnx (`robot/sound/ears.py`, `robot/sound/README.md` for the model and the range —
about 30 cm). «псина, стоп» publishes `/smalldog/explore false` and one zero `/cmd_vel`,
«псина, гуляй» `/smalldog/explore true`; every finished utterance goes out on
`/smalldog/voice` as heard, and the robot answers «стою» / «гуляю» on its speaker.
`robot_explore.sh` passes it (`VOICE=0` not to).

`lidar:=true` is `smalldog_hardware/lidar_node.py`: `3d/tools/stream_pcd`'s TCP feed
(`robot/slam/slam.py`'s reader, imported) republished as `PointCloud2` in `lidar_link`,
the same shape the sim publishes, so `nav.launch.py` is the same launch over either. Needs
`stream_pcd` running on the Pi, and `ros-jazzy-slam-toolbox` plus the Nav2 servers
`nav.launch.py` starts from apt (`ros-jazzy-nav2-controller -planner -behaviors
-bt-navigator -lifecycle-manager -navfn-planner -regulated-pure-pursuit-controller`).
Untested on the robot (**verify**): the SDK's X about the axis against the CAD's
(`yaw_offset`), the odometry scale, and the scan slice against the real floor.
The head parks after 60 s without a non-zero `/cmd_vel` and restarts on the next one
(`lidar_idle_stop:=0` keeps it turning; `/lidar/spin` `std_msgs/Bool` starts or parks it
now). Parked, nothing is published and the map holds. Restarting takes **about 25 s**
(22–28 s measured: the L2 sends nothing until it is back at speed), so a robot woken by
`/cmd_vel` walks that long on the last map — publish `/lidar/spin true` before a nav run
rather than let the run wake it.

The gamepad (a 2.4 GHz "Barrot" pad the kernel drives as an Xbox 360 controller,
`/dev/input/js0`) goes through the `joy` package's `joy_node` and
`smalldog_teleop/joy_teleop.py`: left stick walks and strafes, right stick turns, D-pad
up/down is body height, B stops, Start toggles the gait, LB held is full speed (0.6 of
it otherwise), Back starts and stops the explorer ("SLAM and navigation"). Let go of the stick and it stops; lose the pad and it stops within 0.5 s.
One stick at a time — forward plus a turn is over the servo's speed budget.

Ctrl-C sits the robot down and cuts torque (the node's own signal handler; the loop
leaves through `Runtime.__exit__`). The node refuses to enable torque when the trajectory
topic has two publishers — a leftover MuJoCo launch on the mac reaches the Pi over the
LAN on domain 0 and was the robot's first goal once. Give the robot its own
`ROS_DOMAIN_ID` if the mac is going to run the sim at the same time.

The launch file carries the gait fitted to the servo loop (`robot/README.md`, "The gait
is fitted to the servo"), not the sim's numbers — one point per loop (`FIT` in
`robot.launch.py`): **MODE 2, the default: period 0.95 s, 0.12 m/s, turn 0.9 rad/s**
under the 4.7 rad/s ceiling of the host loop; `mode2:=false`: period 1.35 s, 0.08 m/s,
turn 0.65 under the firmware's 3.28. Either way `stride_max` is raised to admit the
speed, `period_min` is pinned to the same period, and the heading hold is capped at
`yaw_max` 0.2 rad/s. The floor numbers below are the firmware loop's; the MODE 2 point
has walked the bench (`robot/README.md`) and not yet the floor (**verify**). The pin matters for turns: `period_for` counts `|wz| · 0.25` as
speed and cut the cycle to 0.86 s at Nav2's 0.5 rad/s, where the servos lag a foot into
the wrong half of the stride and the turn's direction is a coin toss (`wz +0.5` read
−36° and then +30°, `−0.5` read +34°, IMU, 2026-09-16). Pinned at 1.35 s: `+0.5` →
+103° in 5 s, `−0.5` → −101°. Measured on the floor, 2026-09-15, 2.5 kg, 10.7 V:

| | speed | tracking error, peak | |
|---|---|---|---|
| `imu:=false` (the blind trot, what `walk.py` runs) | 0.11 m/s | 31° | walks; the same 30° `walk.py` sees |
| `imu:=true`, the gait's own `yaw_max` 0.5 | 0.11 | 62° | **tripped** at 0.7 rad on a knee: 0.11 m/s already spends the whole 3.28 rad/s ceiling, and 0.5 rad/s of correction on top demands 4.65 |
| `imu:=true`, `yaw_max` 0.2 (the default) | 0.08 | 44° | walks, 5 s; demand 3.04 rad/s |

44° against a 40° trip held for 0.32 s is not margin. The blind trot veers ~7°/s on this
floor, which is what the hold is correcting, at a speed cost.

**Those runs were on a mirrored robot.** Later the same day `tools/straight_test.py` —
a commanded run measured by the LiDAR (a 2-D scan match of the cloud before and after,
independent of the gait's odometry) and the IMU — read `+wz 0.3` as a **right** turn
(−32° in 4 s, LiDAR −31.5°, IMU −32.8°) and `+vy 0.05` as a **right** crab. Only
`vx` was right. `robot/runtime/calib.json` had the leg names mirrored left/right and
all four roll signs inverted — the bring-up was done belly-up — which made the heading
hold positive feedback: the 0.08 m/s run above spiralled left at the hold's cap, +38°
in 0.4 m. MuJoCo with the gait's output re-wired the same way reproduces the floor
(`wz +0.3` → −41° against +41° correct). Both are fixed in `calib.json`; the pack died
before the fixed map walked, so the first run after a charge is the check:

```bash
python3 tools/straight_test.py --wz 0.3 --seconds 4     # must read a positive turn
python3 tools/straight_test.py --vy 0.05 --seconds 4    # must read a positive left
python3 tools/straight_test.py --vx 0.08 --seconds 6 --log /tmp/st.npz   # then the straight
```

with `robot.launch.py imu:=true lidar:=true` and no pad (`joy:=true` repeats zeros on
`/cmd_vel`). **Verified after the charge, same day**, LiDAR / IMU:

| run | turned | moved | |
|---|---|---|---|
| `wz +0.3`, 4 s | **+38.8° / +39.0°** | — | was −32° |
| `vy +0.05`, 4 s | −3.6° | **+8.9 cm left** | was right |
| `vx +0.08`, 7 s, P hold | +2.5° / +3.9° | 0.38 m fwd, 5 cm left | the 5 cm did not repeat facing the other way: floor, not gait |
| `vx −0.08`, 7 s, P hold | −14° | 0.41 m | the hold at kp 1.5 sits 4–6° off against a ~7°/s veer and loses it backwards |
| `vx +0.08`, 7 s, **PI hold** (`yaw_ki` 0.5) | **+2.7° / +0.2°** | 0.42 m | |
| `vx −0.08`, 7 s, PI hold | **−1.5°** | 0.45 m | |

The walker's `yaw_ki` (0 in the sim, 0.5 in the launch) is the integral term that closes
the P hold's steady error. `odom_scale` is 0.75 from these (0.68–0.82). `level_kp` is
still 0 in the launch: the map is verified, so it can go back to the gait's own — not
yet tried on the floor. The robot's L2 sees ±96° forward: the tool's free-space check
is blind for a backward run and says so.

### Watching the robot

Foxglove is the status page: servos, camera and map in one window, over the LAN.

```bash
ros2 launch smalldog_hardware robot.launch.py imu:=true joy:=true camera:=true foxglove:=true
```

Then on the mac: Foxglove → *Open connection* → `ws://10.0.1.47:8765`, and *Layout →
Import* `smalldog_hardware/foxglove/robot.json`. What it shows:

| panel | topic | from |
|---|---|---|
| camera | `/camera/image/compressed` (jpeg, 720p, ~20–30 fps) | `camera_node.py`: the module's own MJPEG frames through `ffmpeg -c:v copy`, nothing decoded; the panel rotates 180° because the board is mounted upside-down |
| 3D: map, scan, costmap, plan, the robot | `/map`, `/scan`, `/global_costmap/costmap`, `/plan`, `/robot_description` + `/tf` | `nav.launch.py` for the first four; the robot from `robot_state_publisher` |
| diagnostics | `/diagnostics`, 5 Hz | `servo_node.py`: one status per servo (position, goal, error, load, current, volts, the guard's filtered temperature and the raw byte), one for the loop (rate, overruns, bus errors, torque, goal age), one for the IMU. WARN and ERROR follow the guard's own limits; the trip is published once on the way out, so the panel says why the robot sat down |
| plots | `/joint_states` position and effort (Present Load) | `servo_node.py`, every tick |

`camera:=true` needs `ffmpeg` on the Pi (it is), `foxglove:=true` needs
`ros-jazzy-foxglove-bridge` (installed 2026-09-15). The bridge binds `0.0.0.0`, the
sim's binds localhost. Without a camera, `camera_input:=lavfi
camera_device:=testsrc=size=1280x720:rate=20` is a test pattern — that is how the
dry-run on the mac exercises the node. The layout is a plain JSON export; edit it in
Foxglove and export it back over the file.

## Known gaps

- The camera is a topic and nothing subscribes to it but a screen: no rectification, no
  `camera_info`, and `camera.py`'s intrinsics are not published beside it.
- Foot contact is not published under ROS 2 (`/smalldog/foot_load` has no publisher), so the
  launched robot runs with levelling and heading hold but without the landing latch. On
  hardware there are no foot switches either — the topic is a *load*, so the knee servo's
  own load reading can drive it (`smalldog_walker/contact.py`; measured in
  `robot/README.md`).
- Odometry is dead reckoning off the gait (`odom_scale` unmeasured on the robot); the
  GPS is framed but not read. `lidar.Scanner` is not motion-compensated (every point of a
  frame is cast from the end-of-frame pose — 20 mm at 0.2 m/s); `tools/walk_map.py`
  compensates by casting in slices, and measures what the difference is worth.
- `3d/tools/stream_pcd.cpp` reads the L2's IMU and forwards only `linear_acceleration`:
  the sensor's **gyro is read and dropped on the wire**, and so is per-point `time`. Both
  are wanted by anything that deskews or propagates between frames.
- SLAM and the explorer have run on the robot once (2026-09-16): scans at 12 Hz, the map
  building and `map → odom` corrected while the explorer drove — until the stairwell.
  The drop detection above is measured from a held robot, not yet from a walking one.
- Keys reach the teleop only while the MuJoCo window has focus, on press only (GLFW
  auto-repeat dropped); non-printable keys are not forwarded.
- `pkill -f robot_state_publisher` before relaunching, or the next `controller_manager`
  never comes up.

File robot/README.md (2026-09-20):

# SmallDog — the hardware side

Everything that talks to the robot. No ROS, no JAX: `pyserial` and `numpy` are the
dependency list, because this tree runs on the Orange Pi 5 Pro inside a 20 ms tick, and
because `robot/bench` had to run before there was a robot.

| path | what it is |
|---|---|
| `feetech/registers.py` | the SMS/STS control table, transcribed once |
| `feetech/bus.py` | half-duplex driver: read/write, SyncWrite, SyncRead, timing |
| `feetech/loopback.py` | a servo made of bytes, so the protocol is tested every run |
| `bench/bus_probe.py` | what a transaction really costs on this machine → `rl/params/bus_timing.json` |
| `bench/sweep.py` | drives one servo through the identification trajectories → `bench/data/` |
| `bench/fit_bam.py` | those csv files → `rl/params/st3215.json` |
| `bench/hysteresis.py` | the two differential ladders (`holdbi`, `speed`) that measure friction without the fit |
| `bench/torque_hold.py`, `bench/torque_limit.py` | one steady push against a scale on `3d/torque_rig.py`; the volatile `TORQUE_LIMIT` cap |
| `bench/noload_speed.py` | the no-load speed and the duty plateau |
| `bench/lift_test.py`, `bench/*.json` | is foot contact visible in the servo load? the recordings |
| `bench/runlog.py` | the csv format, defined once and used from both ends |
| `bench/pack_sag.py` | a `walk.py --log` recording → the pack's sag, R_eff and the bus draw by gait phase; the untethered measurement `POWER.md` asks for |
| `bench/trot_report.py` | the same recording → heading and attitude from the IMU (`--imu`), footfalls against gait phase, and each joint's delay and reached amplitude |
| `runtime/calib.py`, `calib.json` | which servo is which joint, its zero, its sign — a measurement of one robot, in git |
| `runtime/safety.py` | the limits, and the one place that decides to cut torque |
| `runtime/loop.py` | the 50 Hz tick, controller-agnostic |
| `runtime/mode2.py` | the same tick with the servo's position loop replaced by a PD on the host (MODE 2, open-loop PWM) — `--mode2` on `walk.py` and `policy.py`; `--sine` runs one free servo through it |
| `runtime/walk.py` | the CLI that runs the trot on the robot; `--go S` walks straight for S seconds, `--log FILE.npz` records every tick, `--imu` adds the BMI088 to it |
| `runtime/ticklog.py` | the black box: every tick's feedback, goal, duty, IMU and command into one `.npz` — `walk.py --log`, and the ROS servo node's `log:=` (on by default, a ring of the last 30 min, written on a trip) |
| `bench/leg_probe.py` | is one leg's centre where `calib.json` says? Stand, sweep one joint slowly with its duty capped, read where the foot picks up load. A hand-captured centre is what it catches: `rr_roll` was 6° out and the foot hung 3–7 mm in stance (2026-09-19) |
| `bench/incident.py` | that recording after something broke: how it ended, each joint's peak duty / current / error and when, the body's peaks, and the last seconds tick by tick |
| `sound/` | the speaker: `say "text"` and `bark` on the robot, see `sound/README.md` |
| `slam/slam.py` | LiDAR odometry and a voxel map from the L2. **Not the robot's mapping stack** — `ros2/smalldog_nav` is. Read "SLAM" below before relying on a pose it prints |

Nothing here needs hardware to be exercised:

```bash
python -m feetech.bus --selftest      # packets, checksums, sign-magnitude, SyncWrite
python bench/bus_probe.py --dry-run   # the timing harness
python bench/sweep.py --dry-run --traj all
python bench/fit_bam.py --selftest    # generate a known servo, then find it again
python bench/torque_limit.py --selftest
python bench/pack_sag.py --selftest
python bench/trot_report.py --selftest
python bench/incident.py --selftest   # a synthetic hop and trip, read back
python runtime/calib.py --selftest    # ids, centres, signs, the clamp, the round trip
python runtime/safety.py --selftest   # every limit trips, and only when it should
python runtime/loop.py --selftest     # 2 s of the real loop against a loopback bus
python runtime/mode2.py --selftest    # the host loop, the fold, the runaway, the duty cap
python runtime/policy.py --selftest   # the heading hold against a body that turns late
python runtime/walk.py --dry-run --profile   # ... and the whole trot on top of it
```

The measured servo parameters are collected for outsiders in
[`../ST3215_STS3215_measured_parameters.md`](../ST3215_STS3215_measured_parameters.md);
every number there came from one unit on this bench.

## The 50 Hz budget

At 1 Mbit a byte is 10 µs: SyncWrite of 12 goals 440 µs, SyncRead request 200, twelve
15-byte replies 2520 — **3.2 ms in a 20 ms tick**. One contiguous 15-byte read from
`PRESENT_POSITION` covers position, speed, load, voltage, temperature and current, which
is why `FEEDBACK_LEN` is 15. `SYNC_READ` is not in every firmware; the driver falls back to
sequential reads and reports which path it took.

The wire is never the constraint; the host is: USB frame scheduling, the adapter's latency
timer (FTDI ships at **16 ms** — `/sys/bus/usb-serial/devices/ttyUSB0/latency_timer`, set
it to 1), and the servo's Return Delay. `bus_probe.py` measures the real number and it is an
input to the training randomisation. **Measured, twelve servos, mac + CDC adapter:** full
tick p50 ~3.4 ms, p99 ~4.0 ms. Do not read the bus *scan*'s mean as this number; a scan
spends its time timing out on ids that do not exist.

Two things the bus does, understood and not:

- **Slot 9 of 12 gets a corrupt checksum on a quarter of SyncReads** (`0x22` arrives as
  `0xe2`, payload intact): a talker releasing the half-duplex line a bit-time early, since
  bits 6–7 are the last on the wire. Rotating the id list moves the fault with the slot.
  `Bus.sync_read` drops that frame and re-reads **only that id** (0.47 ms) — a re-read,
  never a repair: masking the bits off would be believing a frame because it is corrupt.
  `--profile` prints `N checksum (M re-read)`; M rising with N is this defect behaving.
- **A rare ~24 ms transport stall**, 0–3 missed deadlines per 500 ticks, almost certainly
  host-side on the mac. The number to trust is the one measured **on the Orange Pi**.
- **The rear legs corrupt their replies under torque** (measured standing, 2026-09-18):
  `rl_knee` ~40 % of its frames, `rr_pitch` ~20 %, the other ten clean, and limp the whole
  bus is at the slot defect's 8 %. The checksum byte is mostly off by `0x80` — the last
  bit cut — but any byte can be hit, so ~3 % of `rl_knee`'s frames pass the one-byte
  checksum with a wrong temperature. Not the L2 (identical with it off), not RETURN_DELAY
  (50 µs changed nothing), not CPU load: the rear signal path, `rl_knee` being the end of
  the rear-left chain. **Reseat or replace the 3-pin leads 42→43 and 31→32** and read the
  exit report's `bad checksums:` line. Until then the driver carries it: a lost or
  header-hit frame is a gap the burst resyncs over and one id re-read alone (a lost reply
  used to cost two port timeouts and twelve sequential reads — the 47 ms read stage that
  was blamed on SLAM), and `Runtime.read` drops a frame whose position, temperature or
  voltage jumps further than a servo can move in a tick, patching a lying temperature and
  keeping the position (a phantom radian at kp 9000 is a full-duty kick). The report says
  which servo, which byte, and how many transactions ran over 8 ms.

## The runtime, in order

`loop.Runtime` takes `source(dt, feedback) -> 12 joint angles` in `robot_params.json`'s
joint order and does the bus, the timing and the safety layer around it. Today the source
is `smalldog_walker`'s analytic trot, imported from `ros2/` (pure Python), the same trot
streamed over ROS 2 by `ros2/smalldog_hardware` (the walker node's trajectory is the
source; `ros2/README.md`, "On the robot"), or the ONNX
policy out of `rl/` through `runtime/policy.py` (`pip install onnxruntime smbus2`; the IMU
driver is `imu/bmi088.py`, I2C, two addresses, `--selftest` first and then `--ids` on the
chip). Neither gets its own idea of a soft limit. **The policy on the floor, 2026-09-15,
on the corrected leg map** (`rl/policy` = 20260915-bc-ft @ 5.6 M, cmd 0.15, measured by
`../ros2/tools/straight_test.py --watch` with the L2): **0.34 m in 5 s, +2.0° of
heading** (IMU +2.6°) — the sim's 0.26–0.35 m for this command. That is with
**And in MODE 2, 2026-09-16** (`--mode2 --kp 5220 --kd 0 --kff 0`, the model's own gains —
`ideas/FAST_SERVOS.md`): `rl/policy_s4`, the policy that only danced in place under the
firmware loop, walks: **20 cm in 1.5 s at cmd 0.2** on the bench, the gait starting 0.6 s
after the command, so ~0.2 m/s under way — the sim's 0.22. Hand over from a level stance
(`--ramp 4 --stand-before 2`); from a nose-down one the policy swings ±17° correcting.
That is with
`policy.py`'s `HeadingHold` on its `wz` command (kp 3, on by default): the policy has no
heading in its observation and arcs −21° in 5 s at cmd 0.2 in the sim on its own. Body
rates while walking are still 0.5–0.6 rad/s std against the sim's 0.1–0.3. Backwards at
−0.15 it turned −17° with the hold saturated a fifth of the time: not straight.

### Bring-up

1. **Program the ids.** `python runtime/calib.py --ids` prints the map: **`<leg><joint>`**,
   leg counted round from the front left, joint counted down the leg — 11-13, 21-23,
   31-33, 41-43. Not `robot_params.json`'s `fl, fr, rl, rr` order; `calib.py`'s `LEG_DIGIT`
   is the one place the two are tied. **This robot's count was made belly-up**, so it
   said "front right" for the leg that is the front left upright, and every left/right
   judgement in the same session went the same way (step 4). Walking forward cannot
   show it; `../ros2/tools/straight_test.py --wz 0.3` and `--vy 0.05` can, in one run
   each: the LiDAR must read a positive turn and a positive left. No id lands in 1..12, so a factory-default servo
   answers as nobody; the ids run to 43, so a scan has to go past 43 (`feetech/bus.py
   --scan` does). Set them over the URT-1 **before assembly**.
2. **`python runtime/walk.py --preflight`** — pings all twelve, reads the control
   registers, checks the host including `latency_timer`. Nothing moves.
3. **Centre the servos, then `python runtime/calib.py --capture`.** Torque off, robot at
   mechanical zero (legs straight down). **Capturing alone is not enough**: as built, six
   joints sat within 330 counts of the 0/4095 encoder wrap and could not reach their soft
   limits (`Servo.to_counts` clamps silently, and wrapping in software sends the leg the
   long way round). Use the servo's own middle-position calibration — write **128 to
   `TORQUE_ENABLE`** with the joint held at zero; it computes `OFFSET` itself. Park
   `GOAL_POSITION` on the present position first, verify by reading back (the write gets
   no reply), then `--capture` records the residual. The soft clamp is ±1.45 rad of roll
   now (it was 0.78), so a joint near the wrap is twice as easy to hit — re-run `--capture`
   before trusting an old `calib.json`. **After a re-assembly, believe the hub, not the
   hand:** the hub goes onto the output in 90° steps, so a centre either moves by a
   multiple of 1024 counts or it did not move. A capture that differs from the old value by
   11° is the held pose, not the servo — that one (2026-09-18, `fl_pitch`) made the RL
   walker rear and hop on the front feet until it was put back. A replacement servo has
   no hub history, so its capture cannot be checked that way: stand the robot and read
   the four knee loads (`bench/leg_probe.py --range 1`); a foot that carries a quarter
   of its diagonal partner's load is hanging, and a slow sweep of the suspect joint says
   where the floor is. The rr foot sits 40 mm outboard of its roll axis, so a roll error
   is first-order in foot height there: 5° lifts it 4 mm.
4. **`python runtime/calib.py --sign all`** moves each joint 8.6° and asks a human which way
   it went — the bus cannot tell which way the fork went on. Prompts are in the robot's
   frame (+X forward, +Y left, +Z up; positive roll swings the foot left, positive pitch
   backward, positive knee folds the shin back), **and bring-up happens belly-up**, where
   left and right reverse. Do not settle roll by eye: command one axis on all four legs at
   once and compare the legs against each other, marking a side first. This robot came out
   **roll −1,−1,+1,+1 (front/rear), pitch and knee −1,+1,+1,−1 (fl, fr, rl, rr)** — after
   the 2026-09-15 correction. The belly-up session had every roll sign inverted and the
   leg names mirrored, and forward walking was fine: only `vy` and `wz` were reversed,
   which turned the heading hold and the roll levelling into positive feedback (the robot
   spiralled left at the hold's cap). MuJoCo with the gait's output re-wired the same way
   reproduces the floor exactly (`wz +0.3` → −41° against +41° correct), which is how the
   two errors were separated without a hand on the robot. Verified on the floor the same
   day: `+wz` → +39°, `+vy` → 9 cm left (`../ros2/README.md`, "On the robot").
5. **`--stand` before `--profile` before the keyboard.** Standing is the first real
   question: whether twelve ST3215 hold 2.5 kg at the commanded height without cooking.

### Foot contact from the servo load

`smalldog_walker/contact.py` gets contact from the knee servo's load minus what the same
leg reads at the same phase hanging free; the loop already SyncReads load every tick, so
it is nearly free. `walk.py --baseline` records the free-air curve, `--contact` uses it,
`--contact-threshold` is **50**.

- **The signal is real and it is latched, not noisy.** Present Load holds dead flat while
  the robot hangs and steps only when what is under the foot changes. Two independent 30 s
  free-air recordings correlate at r = 1.000 with a ~2-unit noise floor on a ~700-unit
  range. Loaded against free, per leg per phase bin, at 2.55 kg: stance medians 65–104
  units, swing medians ~0–10 — 32 to 53 σ of separation.
- **At 1.55 kg (no battery, Pi or payload) it is not there on every leg**: two knees moved
  nothing when set down. That is stiction — below the friction the motor does nothing
  whether the foot is loaded or not, so the duty carries no information. Measure at design
  mass; the plate's position matters (front duty 0.68 against the rear's 0.40 with it
  forward).
- **It had to be measured at a slow gait** (0.02 m/s, period 1.35 s): at 0.20 m/s the trot
  demanded 7.55 rad/s against the limiter, the commanded path was clipped, and the robot
  dragged with the residual peaking in the phase called *swing*. Do not carry 50 back to a
  gait with no clean swing phase to subtract against.
- **The sign is per leg** (knee hubs are mirrored left/right): `ServoContact` takes a
  `{leg: ±1}` dict, and `--contact-sign auto` fills it from `calib.json`'s knee signs, which
  came out identical to the map derived from the load residuals.
- **Baselines**: `runtime/contact_baseline_slow.json` (the measurement gait) and
  `contact_baseline_walk.json` (recorded at 0.14 m/s / 1.20 s). The rate ceiling has since
  moved the fitted gait to 0.11 / 1.35, so `mismatch()` flags the walk baseline on every run
  — re-record it hanging at the new point, or run `--as-commanded --period 1.2 --speed
  0.14`. A period under ~1.2 s at 50 Hz skips phase bins outright (`Baseline.coverage()`
  says which cure: longer period or fewer bins).
- **The threshold of 50 is provisional**: closing it needs a *ground* run at the walking
  gait, which the 40 cm bench cannot give (2.5 gait cycles against 60 bins).
- **Hang it the right way up.** The curve is gravity plus inertia plus friction, and only
  gravity cares which way up the robot is.

What the contact says about this robot: the front feet carry for a duty of 0.68 against the
commanded 0.50 and the rear 0.40–0.43 — the plate sitting forward, so the commanded phase
is not ground truth for contact. The feet themselves are the wrong shape for the floor (a
true R = 13 hemisphere, 2.5 mm Hertz patch at 1.3 MPa, against a sim that assumes μ = 1.2);
PLAN.md step 5 is the measurement that decides whether that matters.

### The guard

`safety.Limits`: 65 °C, 2.0 A held 0.3 s, 9.5 V, 0.70 rad of tracking error, 40° of
body tilt held 0.3 s (`--tilt-deg`; **25° for the RL walker**, `policy.py`'s default and
what `robot.launch.py policy:=` passes — the RL gait's own pitch is under 5° and it is
trained to stand from a 15° hand-over, while the hops under Nav2 that broke the front hip
brackets peaked at +32° and never tripped the 40; **verify** 25 on the floor).

- **Every current limit is in supply amps, and the motor's is higher.** `PRESENT_CURRENT`
  reports the supply current behind the bridge, `d²·U/R`, while the motor carries `d·U/R`;
  2.0 A of supply is d ≈ 0.85 and 2.35 A through the motor. At low duty the register is
  quadratically insensitive — a joint pulling 1 A at 36 % duty reports 0.36 A. These trips
  catch a stalled servo; they are not a thermal limit on a joint working hard at partial
  duty. Standing at 1.55 kg the robot draws 0.4 A while the twelve registers sum to 0.07:
  ~27 mA of quiescent per servo the register does not see.
- **`PRESENT_TEMPERATURE` is unusable while the motor drives**: PWM noise reaches the ADC
  and a 30 °C servo returns isolated bytes up to 150. Every spike is a single sample, so it
  is median-filtered over nine and held 0.5 s; `--profile` counts the discards.
  `Guard.check_at_rest` still refuses on one hot reading before torque comes on.
- **Tracking is 0.70 rad, from the loaded run, not the estimate.** The trot at 2.55 kg peaks
  at 0.61 rad / 35°, reproducible, on a robot doing what it was told (0.35 tripped it after
  one second). `--track-rad` exists because a limit nobody can set is a limit nobody can
  measure. Position itself is trustworthy while driving (0 impossible jumps in 321
  samples). Both selftest fixtures derive from `Limits.q_err_rad`, so raising it cannot
  green a guard that no longer guards.

**What the robot weighs today is not what the limits are for**: 1.55 kg on the table
against 2.49 kg designed, and all of the missing 940 g is body mass. Nothing measured under
load at 1.55 kg transfers — not current, sag, tracking error or the contact threshold — which
is why the bench runs at 2.55 kg with a 1 kg plate.

### The gait is fitted to the servo

`walk.py` refuses to command a trot these servos cannot fly. At 0.20 m/s the trot demanded
7.55 rad/s; the commanded foot path was clipped before a servo saw it and the robot dragged
at 0.067 m/s. `feasible_gait()` finds the shortest period whose demand fits under the rate
ceiling (`joint_rate_ceiling_rad_s` = 3.28 from `robot_params.json`, × 0.95) with the
stride under `max_step`, and caps the speed if none does; `--as-commanded` restores the
old behaviour and names the defect. `walk.py --dry-run --profile`:

| commanded | best period | stride | demand | |
|---|---|---|---|---|
| 0.08 | 1.10 | 22 mm | 3.10 | comfortable |
| 0.10 | 1.25 | 31 mm | 3.06 | |
| **0.11** | **1.35** | **37 mm** | **3.09** | **what anything faster is capped to** |
| 0.12 and up | — | — | — | infeasible at any period |

Ground runs at the previous fit (0.14 / 1.20 s) measured **350–450 mm in 3 s = 0.12–0.15 m/s
against 0.067** — the cap is a faster robot than the drag was. **At 0.11 / 1.35 s: 660 mm
in 8 s = 0.083 m/s**, 75 % of the command, on the 1 m bench at 2.5 kg (three 18650 in the
new case, 12.3–12.7 V, 0.25 A peak, 30° peak tracking error, no drag) — the longer stride
slips more than the 0.14 point did. `feasible_turn()` fits the turn the same way: the teleop's
1.2 rad/s is capped to 0.65; `clamp_profile()` caps the scripted demo's own velocities.

**`--mode2` lifts the ceiling to 4.7 rad/s** — the motor's, not the firmware's. The
firmware's position loop profiles every goal at 7.7 rad/s² and no register lifts it
(`ideas/FAST_SERVOS.md`); `runtime/mode2.py` switches the servos to MODE 2 (a duty on the
bridge) and closes the position loop itself, on the bus, in the time the 50 Hz tick would
have slept. Through the real runtime on one free servo a ±15° sine passes at **0.99 / 0.98 /
0.96 / 0.63** at 1 / 2 / 3 / 5 Hz, against the firmware's 0.74 / 0.25 / – / 0.07. Under it
`feasible_gait()` caps at **0.16 m/s at period 0.95 s** instead of 0.11 at 1.35 (dry run);
what a loaded leg keeps of the 4.7 is **verify** — the stand and the IK trot are the test.
Three facts the runtime handles that `loop.py` never had to: `PRESENT_POSITION` is raw in
MODE 2 (centres shift by `OFFSET`, measured at the switch and checked against the register);
the firmware still cuts torque at 2 A for 2 s and a servo cut that way is dead until torque
is cycled, so the duty is folded back on the current register before that (`i_soft` 1.4 →
`i_hard` 2.0 A per servo, `i_sum` 10 A on the bus); and a bench supply cannot sink the
regen of a hard stop — one servo braking at 3 Hz pushed 12.7 V to 15.2 V, which the pack
absorbs and the guard now holds for 0.1 s rather than tripping on the spike.

**And a fourth: MODE 2 has no torque ceiling unless it is given one.** The firmware never
let a position-mode joint hold full duty (`OVERLOAD_TORQUE` 80 → 20 % after 2 s,
`PROTECTION_CURRENT` bounding a held stall to ~2.3 N·m, "The stall torque"); in MODE 2
only the current fold is left, and it acts after the register has climbed. With the
policy's kp 5220 and no kd, 11° of error is full duty — ~3.3 N·m cold on a fresh pack,
against the `stall` case `3d/fea.py` gives `hip_bracket_A` an interlayer SF of **2.2** at
3.2 N·m. That case became real the day the feet gripped: a sliding dome capped the hip
pitch torque at μ·N, a siped sole caps it at the servo, and the front brackets broke under
the explorer's hops (2026-09-17, robot at its 2.5 kg design mass; the FEA's ground cases
are at that mass and were fine, the stall case does not scale with mass). `--duty-cap
pitch=600` (`walk.py`, `policy.py`; `duty_cap:=` on the launch) is the per-joint
ceiling that stands in for the firmware's: 600 at 12 V is 7 V of drive, which the rig
read as 2.3 N·m. The cost is that joint's no-load speed, which scales with drive. **Which
joints and how much is verify** — the first run after a re-print is the test, and the
exit report prints the peak duty each capped joint reached.

The sim does not have this bug — MuJoCo's feet grip at μ ≈ 1.2 — so `gait.py` is untouched;
fixing it there would move every tuned number in `ros2/` to cure something only the
hardware suffers. The trot stays inside the soft limits on its own (knee 95.3° against
99.1° at 0.45 m/s); the runtime's clamp stays for a source that is *not* the trot.

## The bench, in order

**Build it first.** `3d/bench_rig.py` imports the same `mini_dog.sleeve()` and hub pattern
the robot uses, so the bench holds the servo the way the robot does:

```bash
cd 3d && .venv/bin/python bench_rig.py       # -> out/bench/{step,stl} + the numbers
.venv/bin/python tools/slice_orca.py --machine "Qidi Q2 0.4 nozzle - Copy" \
    --process "0.20mm Standard @Qidi Q2 - Copy" --filament "QIDI НИТ petg черный" \
    --name bench_rig --walls 4 --infill 30% \
    servo_gauge bench_stand bench_arm_s bench_arm_l
```

| part | g | why |
|---|---|---|
| `servo_gauge` | 11.8 | **print this alone first and stop.** Half a sleeve with a hub arm: check a real ST3215 drops into the bore and the four M3 land on the hub before spending five hours on a stand built from the same numbers |
| `bench_stand` | 154 | sleeve + thrust clamp + column; axis **190 mm** above the base so the ⌀140 disc clears |
| `bench_arm_s` | 5.07 | light arm, reach 45 mm — the direct `J_m` measurement |
| `bench_arm_l` | 8.17 | heavy arm, reach 90 mm — the holds and the second free swing |
| `bench_bushing` × 2 | 4.27 ea. | centre the ⌀29 bore on the M6 tip bolt; part of the tip mass |

Arm and bushing masses are weighed off the real print and are in `bench_rig.py`
(`BENCH_FILL`); the slicer was optimistic by 13 % on the arms and 46 % on the bushing.

Non-printed, and the bench does not work without them:

- a supply whose voltage you can **set** (12.6 / 11.1 / 9.9 V);
- **two weighed tip masses**, ~250 g short arm (≥ 227 g or the release is unreadable
  against `tau_c`), 350–450 g long arm (≤ 530 g or `J_load` passes the 35 % share the fit
  warns at). **Compact, one rigid body, outboard of the arm's face, gained along the bolt
  and never in the swing plane**: `J_load` is `m·r²` plus the mass's own moment, and a flat
  disc in the swing plane is over the line on shape alone; a rattling stack brings its own
  friction and damping, which the free swing's decay envelope will charge to the servo.
  Nine 40 × 40 × 3 mm steel squares (339 g) or 79 mm of 50 × 50 × 3 box section (350 g)
  both work; a 500 g calibration disc does not;
- **a clamp — mandatory.** The heavy arm out horizontal is 0.49× the stand's own
  overturning margin and `bench_rig.py` prints `!! IT WILL GO OVER unclamped`;
- 4 × M3 × 6 into the driven hub, 2 × M3 × 10 set screws + nuts for the thrust clamp.

Bolt the arm on so it **hangs straight down** at the servo's centre position: `fit_bam.py`
regresses against `m·g·r·sin(q)`, so q = 0 has to be the hanging position. `bench_rig.py`
prints the exact `sweep.py` line for each arm; weigh the printed arm and correct
`--arm-inertia` if it disagrees.

1. **`--check`** — preflight; prints every control register, nothing moves.
2. **`--traj rock`** — torque off, rock the horn against the play, watch Present Position.
   **Answered: the encoder is AFTER the gearbox** — it moves. The robot can observe its own
   play. Re-run after any gearbox or servo swap.
3. **`--traj freeswing`, light short arm** — the one direct measurement of the reflected
   rotor inertia (73× the knee link's own). `J_m` = `J_total − J_arm`, so the smallest mass
   at the shortest radius that still overcomes friction, **and two different arms**, or a
   heavier J with less friction fits the same fall.
4. **`--traj hold`, heavy long arm, at three voltages** — two linear regressions at
   steady state give the torque constant and the loop gain.
5. **`--traj step` / `triangle` / `reversal` / `chirp`**, same arm, same three voltages.
6. **`--traj holdbi` and `--traj speed`, heavy long arm, three voltages** — the two
   differential ladders `hysteresis.py` reads by subtracting one run from another ("Two
   things the fit cannot find").

The three voltages are not thoroughness: at one voltage back-EMF damping and viscous
friction enter every equation as the same coefficient of ω. **Every run records the servo's
control registers** and the fit refuses to merge runs whose registers disagree — a fit is
only valid for the P/D/I, dead zone, punch and acceleration the servo had at the time.

Power the servo from the supply directly, never through the URT-1 or USB (a stalled ST3215
draws 2.7 A). `sweep.py` aborts on temperature, current and travel and always leaves torque
disabled; the servo's own protection registers are read and never written.

## How the fit works, and what it can and cannot find

`fit_bam.py` runs analytic passes first and a trajectory refinement last, because the
analytic passes are where the identification happens:

| pass | gives | from |
|---|---|---|
| **hold ladder, both ways** | **`tau_c`, `mu_load`** | the up/down difference at each angle — a measurement, not a fit |
| free swing | `J_m`, `tau_c` | release acceleration, or the period if it oscillates |
| holds | `k_u·R`, `kp/R`, dead-zone intercept | two linear regressions at ω = 0 |
| saturation | `1/R`, `k_e/R` | one regression over the duty-pinned samples |
| reversal | dead zone | the smallest command that moves the joint |
| refinement | everything, a little | Powell over a diverse subset — **opt-in, `--refine`** |

- **The fit does not run in the model's own coordinates**: the instruments only ever see
  `k_u·R`, `kp/R`, `k_e/R` and `1/R`, so fitting R and k_u separately lets the optimiser
  walk along `k_u·R = const`. On synthetic data R recovered to 0.1 % while k_u sat 34 % off.
- **The refinement is Powell, not `least_squares`, and off by default**: the residual is
  not smooth (dead zone, punch, backlash, saturation are switches), finite differences read
  an optimality of ~10⁹ and `trf` converges after a step of zero. Powell still came back
  3.5× worse than the analytic seeds on synthetic data, so the guard discards it; `--refine`
  can decline but not damage. With the full data set it diverges (`kp` at its bound, `k_e`
  11.3, an implied no-load speed of 1.06 rad/s against a measured 3.86) — a fit reaching for
  torque the electrical model cannot supply, and adding friction did not change its
  character.
- **`--selftest`** generates data from a *known* servo and finds it again: R 3.7 %, k_e 2.2 %,
  k_u 6.5 %, kp 14.8 %, J_m 5.2 %, tau_c 24.5 %. `b_v`, `deadband`, `punch`, `theta_bl` are
  not recovered because the 8 s self-test truncation stops before the trajectories reach the
  commands they need; run them in full on hardware. `mu_load` is the opposite case: measured
  cleanly on hardware and *not* recoverable from the model's own output, because the smooth
  law has no stick — the self-test is indicting the model, not the experiment.
- **A run no pass consumes changes no parameter.** The analytic passes select on
  `freeswing`, `hold` and `holdbi`; everything else reaches the fit only under `--refine`.
  `check_identifiable` names every trajectory in the directory no pass reads. Do not read an
  unchanged fit as agreement.
- **`--seconds` truncates, and a run whose measurement is a difference between its halves
  is halved, not shortened.** `holdbi` is 36 s against a 25 s default and once silently lost
  two thirds of its descending rungs. `Run.WHOLE_RUN` names those.

`rl/params/st3215.json` is the current fit: 44 runs at three voltages. Read its `source`
string before quoting it.

### The load-dependent friction term

`actuator.Params.mu_load` — friction per N·m crossing the gearbox — measured by
`fit_bam.seed_from_holdbi` off the bidirectional ladder, running **first** among the
analytic passes because the free swing subtracts `tau_c` and had been using half the real
value:

| | before | after |
|---|---|---|
| `tau_c` | 0.084 | **0.184** |
| `J_m` | 0.0240 | **0.0165** |
| `mu_load` | — | **0.286** |
| position RMS | 8.96° | 8.84° |
| current RMS | 1.25 A | 1.01 A |

The ladder and the free-swing fit are independent routes that had disagreed by 2× and now
land on 0.184 and 0.186. `J_m` moving is a consequence.

### Static friction

`simulate()` uses Karnopp: below `v_eps`, friction opposes the net applied torque up to
`tau_c + mu_load·|tau_t|` and the shaft is held; a hold approached from two sides settles at
two duties. The magnitude is uncalibrated (0.72 V half-difference on the model against the
real 0.29). On the training path `friction()`/`motor_torque()` cannot do this — MuJoCo owns
the load there — so stick comes from MuJoCo's own `frictionloss` = `tau_c`
(`rl/CLAUDE.md`). A refit against the Karnopp model moved `J_m` +20 % and nothing else,
with one RMS better and one worse; it was **not** adopted.

### The stall torque, in newton-metres

**4.50 N·m at 12 V**, on `3d/torque_rig.py` — a printed C-frame with a 170 mm arm pressing an
M6 anvil onto a 2 kg coffee scale. `mini_dog.py`'s `SERVO_STALL_NM` was this number until the
full-duty ladder below; it is 3.2 now.

| `TORQUE_LIMIT` | d·U | scale, cold | τ |
|---|---|---|---|
| 200 | 2.41 V | 0.408 kg | 0.680 N·m |
| 350 | 4.13 V | 0.780 kg | 1.300 N·m |
| 450 | 5.27 V | 1.100 kg | 1.834 N·m |

k_u = **0.400 N·m/V**, friction intercept **−0.30 N·m** (a third independent read on
`tau_c`), residuals ±0.05. The register routes (7.4 N·m, two channels agreeing to 0.3 %)
and the datasheet (2.94) were both wrong, in opposite directions; there was never one scale
error to find. `k_t` and `R` stay unresolved because `PRESENT_CURRENT` is unusable below
~0.2 A.

- **Do not read a scale off `sweep.py --traj stall`.** Its 0.8 s bursts are right for the
  electrical fit and wrong for a scale, which reads the arm's inertia and its own filter
  ringing on top (920 g in bursts against 780 held — a constant ~130 g offset that corrupts
  the slope). `bench/torque_hold.py` is one steady 8 s push with a per-second profile.
- **The torque decays 4–7 % in 8 s** as the winding warms and R rises; the cold value is the
  one a leg uses in a transient and the one recorded. `rl/actuator.py` has no thermal term.
- **Fixture faults produce convincing wrong answers.** A kitchen scale bridging the 33 mm
  jaw rocks; on the table the reaction goes out through a bench clamp, and one clamp let the
  stand lean its own weight onto the scale (+70 g every rung). The encoder cannot see any
  of this. Next time: scale in the throat on a rigid plate wide enough for its feet.
- **`TORQUE_LIMIT` is volatile** (SRAM, reloaded from `MAX_TORQUE` on power-up).
  `bench/torque_limit.py` writes it, reads it back, and refuses while torque is enabled.
  Cap before every session and after every supply change.
- **The line bends above ~5.5 V of drive, and 4.50 is the extrapolation that did not know
  it.** Second unit, the rig rebuilt with the scale on a plate, supply dropped to 8 V so
  full duty fits under a 2 kg scale, 5 s holds:

  | supply | cap | d·U | scale | τ | |
  |---|---|---|---|---|---|
  | 7.88 | 500 | 3.94 | 905 g | 1.51 | cold |
  | 7.80 | 700 | 5.46 | 1165 | 1.94 | cold |
  | 7.80 | 850 | 6.63 | 1237 | 2.06 | warm |
  | 7.80 | 1000 | 7.80 | 1350 | **2.25** | warm |
  | 7.81 | 700 | 5.47 | 1065 | 1.78 | warm repeat, −8 % for +7 °C |
  | 11.90 | 500 | 5.95 | 1245 | 2.08 | warm |
  | 11.90 | 600 | 7.14 | 1378 | 2.30 | warm |

  Duty is honest at every rung (`PRESENT_CURRENT` = d²·U/R to 3 %, R 3.94 → 4.48 Ω as the
  winding heats), and the same d·U gives the same torque at 8 V and 12 V, so this is the
  motor: 0.40 N·m/V below 5.5 V of drive, ~0.20 above it. Full duty at 12 V extrapolates
  to **~3.1–3.3 N·m** cold, not 4.50 — a number for a 3 kg scale to confirm.
- **And the servo will not hold full duty.** Two protections, both stock, both met on this
  ladder: `OVERLOAD_TORQUE` 80 / `PROTECTION_TIME` 200 / `PROTECTIVE_TORQUE` 20 — any duty
  above 800 is cut to 20 % after 2 s (cap 850 held 1.43 A for 2 s and dropped to 0.07); and
  `PROTECTION_CURRENT` 310 × 6.5 mA = **2.0 A** / `OVERCURRENT_TIME` 200 — torque cut to
  zero (cap 1000, push 2: 2.23 A, arm fell back 64 counts). 2.0 A through R ≈ 4 Ω is
  d·U ≈ 8 V, so **the sustained stall is ~2.3 N·m at any pack voltage**; above it a leg has
  2 s. The 850/1000 rungs were read with `OVERLOAD_TORQUE`/`PROTECTIVE_TORQUE` at 100 on
  the loose unit, restored to 80/20 and read back — `sweep.py`'s rule stands for robot
  servos. What the model carries is an open decision (PLAN.md 3d).

### The no-load speed, and the plateau

**3.86 rad/s at 12.1 V** with `bench/noload_speed.py`, hub free, no arm; the vendor's 4.71
was 22 % high. `SERVO_NOLOAD_RADS` is 3.86.

| `TORQUE_LIMIT` | d·U | ω from position | ω from `PRESENT_SPEED` |
|---|---|---|---|
| 1000 | 12.0 V | **3.864 rad/s** | 3.835 |
| 800 | 9.6 | 3.851 | 3.835 |
| 600 | 7.2 | 3.093 | 2.953 |
| 400 | 4.8 | 2.077 | 1.994 |

The register's speed LSB is verified as a side effect (1–5 %). **The finding is the
plateau**: 800 and 1000 read the same, the register sits at 2500 counts/s for both, and the
rungs below are linear through the origin at 0.43 rad/s/V (k_e = 2.32 V·s/rad). **It is the
position loop's profile, not the bridge**: `noload_speed.py --pwm` (MODE 2, open-loop duty)
on the second unit reads 2.02 / 3.06 / 4.10 / 5.02 rad/s at duty 400 / 600 / 800 / 1000 —
linear through the origin, k_e = 2.39, no plateau — while position mode on the same unit
stops at 3.88 with the same flat 2500. So the 4.50 stall stands as far as this test can
say; it shows the motor reaches full duty in MODE 2, not that the position loop applies it
at zero speed — the torque rig at `TORQUE_LIMIT` 800 and 1000 is that check. `rl/actuator.py`
still frees to 5.9; what it needs is a rate cap on the goal. Both tools leave `TORQUE_LIMIT`
at their last rung; re-cap before the arm goes back on.

### Two things the fit cannot find, and the ladders that measure them

1.066 kg on the 90 mm arm at 8 / 10 / 12 V, `sweep.py --traj holdbi` and `--traj speed`,
read by `hysteresis.py`. The law is `tau_c·sign(w) + b_v·w`, both independent of load, so a
friction that grows with the torque carried has nowhere to go except `k_u`, and `b_v` sits
pinned on its bound however much data it is given. Both ladders are **differential**: a
difference between two runs of the same trajectory.

| | 8 V | 10 V | 12 V | must it move with V? |
|---|---|---|---|---|
| position-loop stiffness, N·m/rad | 28.1 | 34.4 | 40.9 | **yes**, 3.44 per volt |
| effective torque constant, N·m/V | 0.636 | 0.611 | 0.596 | no |
| friction at a hold, unloaded, N·m | 0.192 | 0.181 | 0.186 | no |
| …per N·m of load carried | 0.286 | 0.295 | 0.251 | no |
| kinetic Coulomb at zero load, N·m | 0.161 | 0.160 | 0.168 | no |
| total speed-proportional, N·m·s/rad | 1.403 | 1.364 | 1.334 | no |

The four rows holding still across a 1.5× supply range is the check that they are physical.

1. **Friction grows with load: +0.28 N·m per N·m carried, on a 0.19 N·m floor.**
2. **The stiffness was 40 % low and the error hid inside the friction**: a one-way ladder
   bills the friction band to elasticity. 40.9 N·m/rad at 12 V, not 28.8.
3. **`b_v` is not resolvable on this bench.** The speed ladder pins the *total*
   speed-proportional torque to 1.37 N·m·s/rad within 5 %, but that is `b_v + k_t·k_e`,
   back-EMF alone is 1.31, and neither term depends on supply, so the voltage sweep cannot
   split them. Use the total; it is what a simulator needs (`MJ_DAMPING`).

One loose end: at a commanded 2.0 rad/s the servo reaches 1.8 and no more, at 0.74 rad of
error, without the duty pinning. `D_COEF` is 32 and `rl/actuator.py` models `kd = 0`; an
internal output clamp would look the same, and this data does not separate them.

### Unit to unit

The same two ladders on three more ST3215s, heavy arm, 12 V only, in `bench/data-servo2/`,
`data-servo11/`, `data-servo21/` (`hysteresis.py --data <dir>`). Unit 2 was a loose servo
14 counts from the wrap and was recentred with the middle-position command (`OFFSET`
−1918); 11 and 21 came off the robot and ran with `--centre` at their hanging position so
`calib.json` still holds.

| | unit 1 | unit 2 | #11 | #21 | spread |
|---|---|---|---|---|---|
| position-loop stiffness, N·m/rad | 40.8 | 39.7 | 39.2 | 40.6 | ±2 % |
| effective torque constant, N·m/V | 0.596 | 0.578 | 0.574 | 0.588 | ±2 % |
| friction at a hold, unloaded, N·m | 0.186 | 0.117 | 0.144 | 0.161 | **0.64–1.01×** |
| …per N·m of load carried | 0.251 | 0.380 | 0.328 | 0.302 | **0.88–1.33×** |
| kinetic Coulomb at zero load, N·m | 0.168 | 0.124 | 0.153 | 0.173 | 0.67–0.94× |
| total speed-proportional, N·m·s/rad | 1.334 | 1.326 | 1.276 | 1.284 | ±2 % |
| no-load speed, position mode, rad/s | 3.86 | 3.88 | — | — | |

The electrical rows and the profile cap are the same servo to 3 %; the gearbox is not, and
the unit with the lowest floor has the highest load slope — two numbers, not one grease
number. Each unit's static and kinetic floors agree with each other, so the spread is the
gearbox, not the read. **A rig bind is a friction reading**: #21's first pass, with the
arm bolt rubbing at the centre, read every row 5–10 % high (floor 0.181, stiffness 42.8)
and was replaced; turn the hub by hand through the centre before every run.
`rl/params/domain_rand.json` carries it: `tau_c` ×0.55–1.20,
`mu_load` ×0.75–1.55, `kp` ×0.85–1.15 (the observed spread with a margin for the eight
unmeasured), all `measured` now.

## SLAM

`slam/slam.py` takes `stream_pcd`'s feed off the Unitree L2, registers every frame with
KISS-ICP and accumulates a 5 cm voxel map, serving it in the same ULF3 format so
`3d/tools/pcview.py --stream` draws the map instead of the sensor.

**It is not what maps the room.** `ros2/smalldog_nav` does that — a 2-D slice of the same
cloud into slam_toolbox, with the gait's own dead reckoning as odometry, Nav2 on top and a
frontier explorer that covers a room by itself. This file is the other answer: full 3-D,
no odometry input at all. It is kept, and measured, so that staying with the 2-D route is
a decision rather than an accident.

### What it does, measured

`../ros2/tools/walk_map.py` trots the real gait through `scene_room.xml` — the same room
`tools/explore.sh` drives — casting the measured L2 pattern into this odometry and scoring
both trajectory and map against MuJoCo's truth. **The navigation cheats on ground truth on
purpose**: this measures perception, not steering. One frame per registration, motion
distortion modelled:

| path | run | walked | net turn | end | max | yaw max | map rms | map rms, truth pose |
|---|---|---|---|---|---|---|---|---|
| stand still | 8 s | — | — | 5.9 cm | 9.3 cm | 1.8° | 29 mm | 18 mm |
| straight | 30 s | 2.04 m | 1° | 5.7 cm | 7.2 cm | 2.0° | 39 mm | 47 mm |
| spin on the spot | 8 s | 0.32 m | 156° | 14.4 cm | 15.6 cm | 6.2° | 58 mm | 35 mm |
| both rooms + doorway | 185 s | 21.50 m | 539° | **2.8 cm** | 17.7 cm | 9.0° | 61 mm | 55 mm |

**In this room it works.** 2.8 cm after a 21.5 m tour through a doorway, and a map at
61 mm rms against the 55 mm the same points score when placed by perfect truth — that is
the sensor's own noise, not the odometry's. The trot is not a problem for it: the body's
2.2 Hz bob costs almost nothing.

`map rms, truth pose` is the same points placed by MuJoCo's truth instead of by the
odometry. It is the map a perfect pose would give, so the gap between the columns is the
odometry's bill and the column itself is the sensor's.

### And then it does not, and the difference is the room

The same code, the same settings, three scenes, robot standing perfectly still:

| scene | max drift, stationary |
|---|---|
| `scene_room.xml` in sim — two chambers, 0.5 m walls, cluttered | 0.09 m |
| a 6 × 4 m sim room with 2.4 m walls, sparsely furnished | 0.25 m |
| **the real capture — the L2 on the robot, in a real room** | **0.48 m** |

The last row is `3d/ref/lidar/l2_onboard.pcd`: 120 real frames, 10 s, the sensor bolted to
the standing robot, replayed through `Odometry` exactly as the node runs it. It is not the
decimation — the capture is 1:11 by stride, and decimating the sim the same way moves it
0.094 → 0.106 m. It is not tuning either: registration voxel swept 0.05–0.40 m, ICP
threshold 0.05–0.60 m and `min_range` to 0.5 m all still leave 0.20–0.61 m, with no
ordering to them.

**Why, and why it scales with the room.** The beam spins in a plane through the axis at
`BEAM_HZ` = 215.7 rev/s while that plane precesses at `PREC_HZ` = 4.354, so one 83 ms
frame is **18 meridian sweeps** (counted directly in the capture: 18 axis passes, against
the 18.0 the two rates predict), each smeared 7.3° in azimuth. A frame is a fan of lines
across the room, not a sample of its surfaces, and the next frame's lines land elsewhere
because the two rates are deliberately incommensurate. Point-to-point ICP fitting one fan
of lines to a map of other fans has an aperture problem and slides — and the bigger and
emptier the room, the further apart those lines land on any one surface, which is the
ordering in the table. Two controls pin the cause down: feeding the same cloud twice
drifts exactly 0, and sampling the *same* cone uniformly instead of along meridians drops
the drift from 0.24 m to 0.009 m.

This is why a sensor of this class ships with Point-LIO rather than plain ICP: the IMU is
what carries the pose between frames that individually cannot fix one.

**Stacking frames is the same story from the other side.** On the real capture, where a
single frame is not enough, registering several at once fixes it outright:

| frames per registration | pose rate | max drift, real capture |
|---|---|---|
| **1 (as committed)** | 12 Hz | **0.48 m** |
| 2 | 6 Hz | 0.14 m |
| 4 | 3 Hz | 0.033 m |
| 12 | 1 Hz | 0.016 m |

In `scene_room.xml`, where a single frame already suffices, the same `--stack 4` makes the
tour *worse* — 41 cm against 2.8 cm — because all it adds there is 23° of rotation per
window smeared into a cloud ICP treats as rigid. Both halves are the same missing
quantity: rotation during the window.

### The operative conclusion

**The sim room flatters this frontend, and the only real data we have does not.** A
measurement taken only in `scene_room.xml` would have said 2.8 cm over 21.5 m and been
wrong about the robot. That caution is not specific to this file — `smalldog_nav`'s own
run is sim-only too, by its README's own admission.

What follows, in order:

1. **`3d/tools/stream_pcd.cpp` drops the gyro.** It reads `LidarImuData` and forwards
   `linear_acceleration` only. The L2's angular rate is being read off the sensor and
   thrown away on the wire, and per-point `time` with it. Both are wanted by anything that
   deskews or propagates between frames, on either route. One field on an existing struct —
   do this first, whatever is decided about the rest.
2. **Capture the real L2 while the robot walks.** Everything above that involves walking is
   simulated; the one real recording is of a robot standing still. `--record` on the node
   already writes the frames, and `--replay` scores them offline. That is the cheapest
   real measurement left and it gates any claim about either frontend.
3. Only then the frontend choice — Point-LIO on the Pi against continuing to carry this —
   and it is not urgent while `smalldog_nav` is the thing that maps.

**Not measured, and do not assume:** any of this on the Pi. The timings
(p50 8–21 ms a frame against the 83 ms between them) are a container's CPU, not an
RK3588's, and the Pi is not installed — `PLAN.md` steps 9–10.

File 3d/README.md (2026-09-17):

# Mini Robot Dog — V1 printed CAD

Parametric 12-DOF quadruped built around **12 × Feetech/Waveshare ST3215 (STS3215)** bus
servos. Everything structural is FDM-printed (PETG/ASA); no aluminium, no machining, no
external bearings — per `mini_dog_codex_handoff.md`.

The model is generated by [mini_dog.py](mini_dog.py). Re-run it after changing any parameter:

```bash
.venv/bin/python mini_dog.py     # writes out/step, out/stl, out/bom.json
.venv/bin/python render.py       # writes out/view_*.png
.venv/bin/python fea.py --all    # strength check - run after every change
.venv/bin/python export_sim.py --check   # writes out/sim/ (URDF + MJCF, flat + terrain)
```

Any change is re-checked for strength **and** re-exported to both simulations in the same
pass; the workflow and the current baseline are in [CLAUDE.md](CLAUDE.md).

## Servo interface — measured, not guessed

From the Waveshare ST3215 wiki downloads in [ref/](ref/), measured with [tools/](tools/):

| | value | source |
|---|---|---|
| case | 45.22 × 24.72 × 35.00 mm | `ST3215.step`, `ST3215.pdf` |
| rotation axis | along the **35 mm** dimension, 10.11 mm from the output-side end face, centred in the 24.72 width | drawing SCS215 |
| driven hub plate (25T side) | ⌀19.2, outer face **+20.30** from the case mid-plane | STEP |
| passive hub plate | ⌀19.2, outer face **−16.95** (recessed 0.55 into the case base, ⌀25 pocket) | STEP |
| hub-to-hub mounting span | **37.25 mm** | drawing |
| hub fixing | 4 × **tapped M3** on a **⌀14** bolt circle, at 0/90/180/270° | **hardware** — the STEP says ⌀2.5 and is wrong |
| hub plate thickness | driven **2.50** (z 17.80…20.30), passive **2.20** (−16.95…−14.75) | STEP |
| case side faces | **no threaded holes** — the case is gripped by form, not by screws | STEP |

That last row drove the whole architecture.

## Joint architecture

```
proximal link ──► SLEEVE : rectangular tube around the servo case, open on the axis.
                          Reaction torque goes into the 45×35 flats, not into screws.
                          Two M3 thrust screws through its back wall take up the play.
distal link   ──► FORK   : two arms lying on the two aluminium hubs, 4 × M3 each.
                          The arms straddle the sleeve, so the servo is also captured axially.
```

- the servo is **never** loaded through a printed thread or a single-shear horn;
- assembly = slide the servo into the sleeve, set the two thrust screws, bolt the fork to
  both hubs;
- the stock passive hub is used as supplied — no 628/685 bearings.

Range of motion is measured by swept boolean interference against the real solids
(`rom_scan()`), with the thrust screws, the hub screw heads, the cradles, the camera and
the GPS mast in the static set. It reads roll ±90, pitch ±90, knee ±110; ±90 is where the
scan window stops, not where the leg fouls.

### The thrust clamp

A form fit needs clearance to assemble, and clearance is backlash: on `CLR` alone the case
rocks ~±0.9° in its sleeve, ~±2.5° at the foot with three joints stacked. Two M3 jack
screws through the sleeve's back wall (−x end, away from the cable window) at y = ±5.5 push
the case forward onto the two legs the cable window leaves in the front wall. That **pins**
the case: turned either way it drives itself onto one thrust screw at the back and the
opposite front leg — play closed by geometry, not friction, which is why there are two.
Each threads into an M3 nut in a side-loaded channel in the lug.

Two rules, both measured:

- **Do not slit the sleeve into a C.** The −x end wall is the tube's only crossing of y = 0
  (the cable window ate the front one). A slit costs `thigh_A` 1.1 → 0.6 inter-layer SF at
  stall and 2.65 → 12.2 mm of deflection; tying the front wall back across the window
  recovers none of it.
- **Everything the clamp adds stays inside r < 23 mm of the joint axis**: the distal fork's
  spine sweeps 23…34 over the sleeve's length. The lug corner sits at 21.6 and is fine; a
  DIN 912 cap head on an M3 × 10 reaches **r = 24.2** and binds the joint over ±2…38° —
  the first assembled leg did exactly that. So the screw is **headless: an M3 × 10 set
  screw** (r = 20.96, 1.43 mm spare); × 12 still clears, × 14 does not. A button head
  reaches 22.98 and a countersunk head 23.08 — neither is a clearance. `thrust_clear()`
  prints the margin on every run; `thrust_bolts()` is in every `rom_scan`.

### The cradle joint

The hip-roll cradles are **not part of the tray**: `cradle_front` and `cradle_rear`, one off
each, each carrying both of that end's roll servos, four M3 × 12 per end. The tray went from
213 × 110 × 50 mm / 208 g to 126 × 92 × 50 / 127 g (cradles 38 g each), and a tray change
stopped meaning "reprint four cradles and unbolt four servos".

- **One part per end, not four quarters**: the two halves' rails overlap on the centreline
  (each reaches y = ∓14), so the quarters are not separable bodies.
- **Four screws and a register.** The screws see 22 N axial and 28 N shear at worst —
  nothing. What they do not replace is 795 mm² of welded face for **stiffness**: the roll
  axis is 27 mm outboard and the foot 187 mm below, so 0.1 mm of slop at the flange is
  0.7 mm at the ground. Each screw runs through a ⌀`CRADLE_REG_D` = 7 spigot, `CRADLE_REG`
  = 2 mm proud, into a pocket in a locally thickened tray wall. Spigots take shear and
  torsion; screws only clamp.
- **Where the screws may go is decided by the fork.** The flange is only `CRADLE_T` = 4 mm
  deep (its outer face is `FORK_GAP` behind the roll fork's rear arm) and an M3 nut does not
  fit in 4 mm, so nut bosses run out to `CRADLE_BOSS_X` = 71.5 (servo case at 72.5). That is
  legal because past the flange the only thing in the way is the arm's `ARM_R` disc — the
  spine's annulus is swept only outboard. Screws at (±17, ±7), nearest boss corner at
  r = 14.1 against `ARM_R` = 13.5. `rom_scan` checks the arm; `cradle_clear()` checks a
  driver reaches the heads; `cradle_head_clear()` checks the heads against the battery
  module (1.65 mm ISO 7380 heads on a seat 1.25 mm off the pack — hence `CRADLE_CB` = 2 mm
  of counterbore).
- **The screws land in heat-set inserts — the one place on the robot they do.** The nut
  they had sat in a side channel "toward the centreline", into the rail box, which is solid
  there: a sealed cavity that printed and passed every check. A pocket open to the servo
  bore instead hollows the boss and puts `land3g` at the strap's edge where the boss ends
  (`--orient` SF 1.33 → 0.77); moving the bolts to |z| = 7 recovers it (2.06) but moves
  the tray's seats, and a tray is printed. So: bolts stay at ±10.5, the boss stays solid,
  and an M3 insert (⌀5.0 × 6 knurled body, the ones bought; hole `INS_D` = 4.4, **verify**
  on a coupon) goes in **from the flange side, through the register spigot**, pressed
  1.5 mm past the flange face to bottom on a 1 mm lip in the boss. Push it with an M3 screw threaded
  into the insert and the iron on the screw's head — a stepped insert tip stops at the
  spigot. Screw tension pulls the insert into the lip, never out. The spigot's wall goes
  1.8 → 1.3 mm — thin; keep the iron off it and let the insert do the pushing. `cradle_insert_clear()` sweeps the bore from open air to the seat, checks
  the lip is there and that the M3 × 10's tip stays inside the boss.
- **The flange is a frame**, and its opening is what lets the rear connector panel out.
- **`cradle_front` is the weakest printed part** — inter-layer SF 1.33 at `land3g`
  (`fea.py --orient`). The first FEA of it fixed a 1.4 mm notch and a 27.6 mm step in the
  strap (peak 53.7 → 29.7 MPa); the rest is structural, and the three obvious fixes each
  made it worse. `CLAUDE.md` has the rule.
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

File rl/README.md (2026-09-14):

# SmallDog RL

The third consumer of the CAD, after [`3d/`](../3d) and [`ros2/`](../ros2): an
RL walking policy trained in MuJoCo and run on the robot at 50 Hz, replacing the
analytic IK and the hand-written trot in `ros2/smalldog_walker`.

This tree reads the **generated** description in `ros2/smalldog_description`
(MJCF, meshes, `robot_params.json`) and never writes to it. `3d/CLAUDE.md`'s rule
holds here too: the simulated robot is output of the CAD, and a mass, a limit or
an axis that is wrong in simulation is wrong in `3d/mini_dog.py`. Model changes
that exist only for training — a fitted actuator, backlash, per-environment
randomisation — are applied programmatically through `mujoco.MjSpec` at load
time (see `checks/imu_placement.py` for the mechanism), so nothing hand-tuned
ever lands in a committed XML.

No CadQuery is needed here. That is deliberate: the CAD lives on the mac,
training happens on a CUDA machine, and the repository is the only thing that
crosses between them.
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

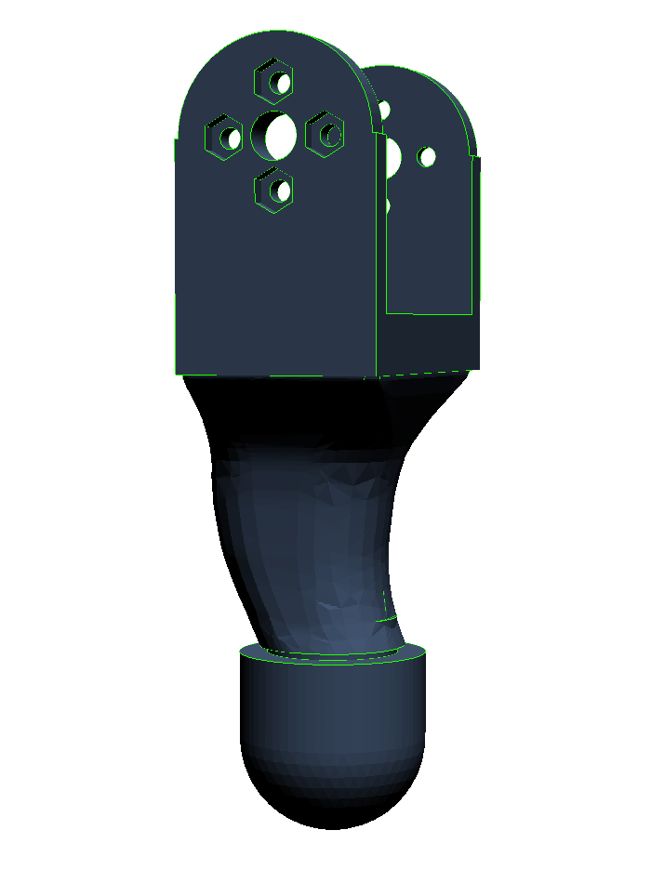
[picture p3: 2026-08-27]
ros2/docs/fl_shin.png

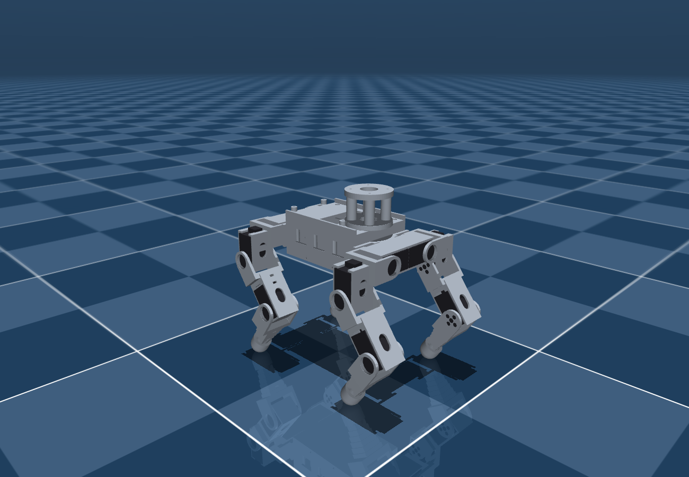
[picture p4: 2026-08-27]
ros2/docs/stand.png

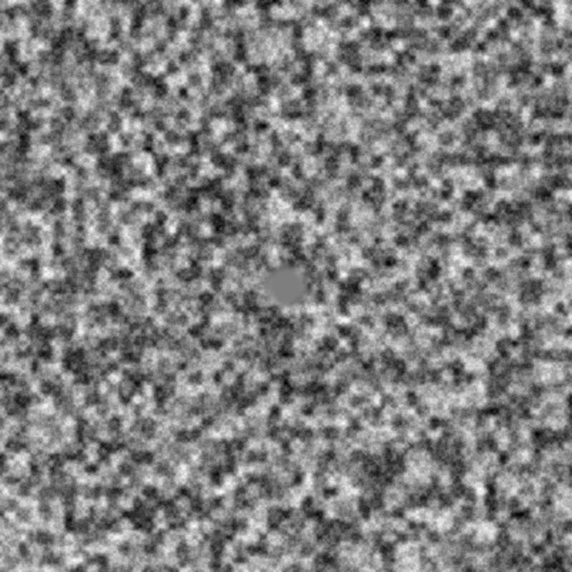
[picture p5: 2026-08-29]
ros2/smalldog_description/meshes/terrain.png

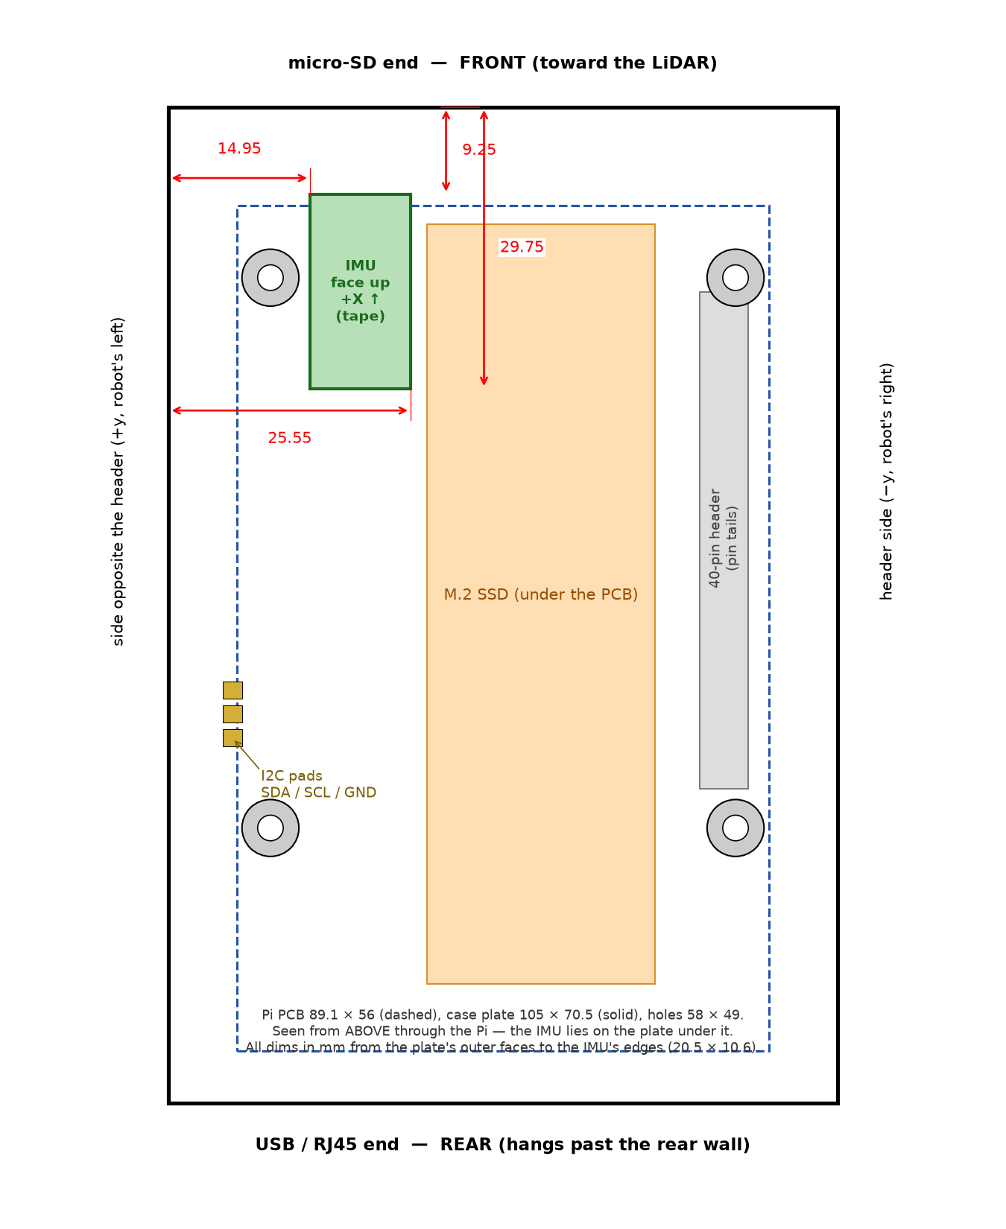
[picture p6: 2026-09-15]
3d/ref/imu/imu_in_case_top.png

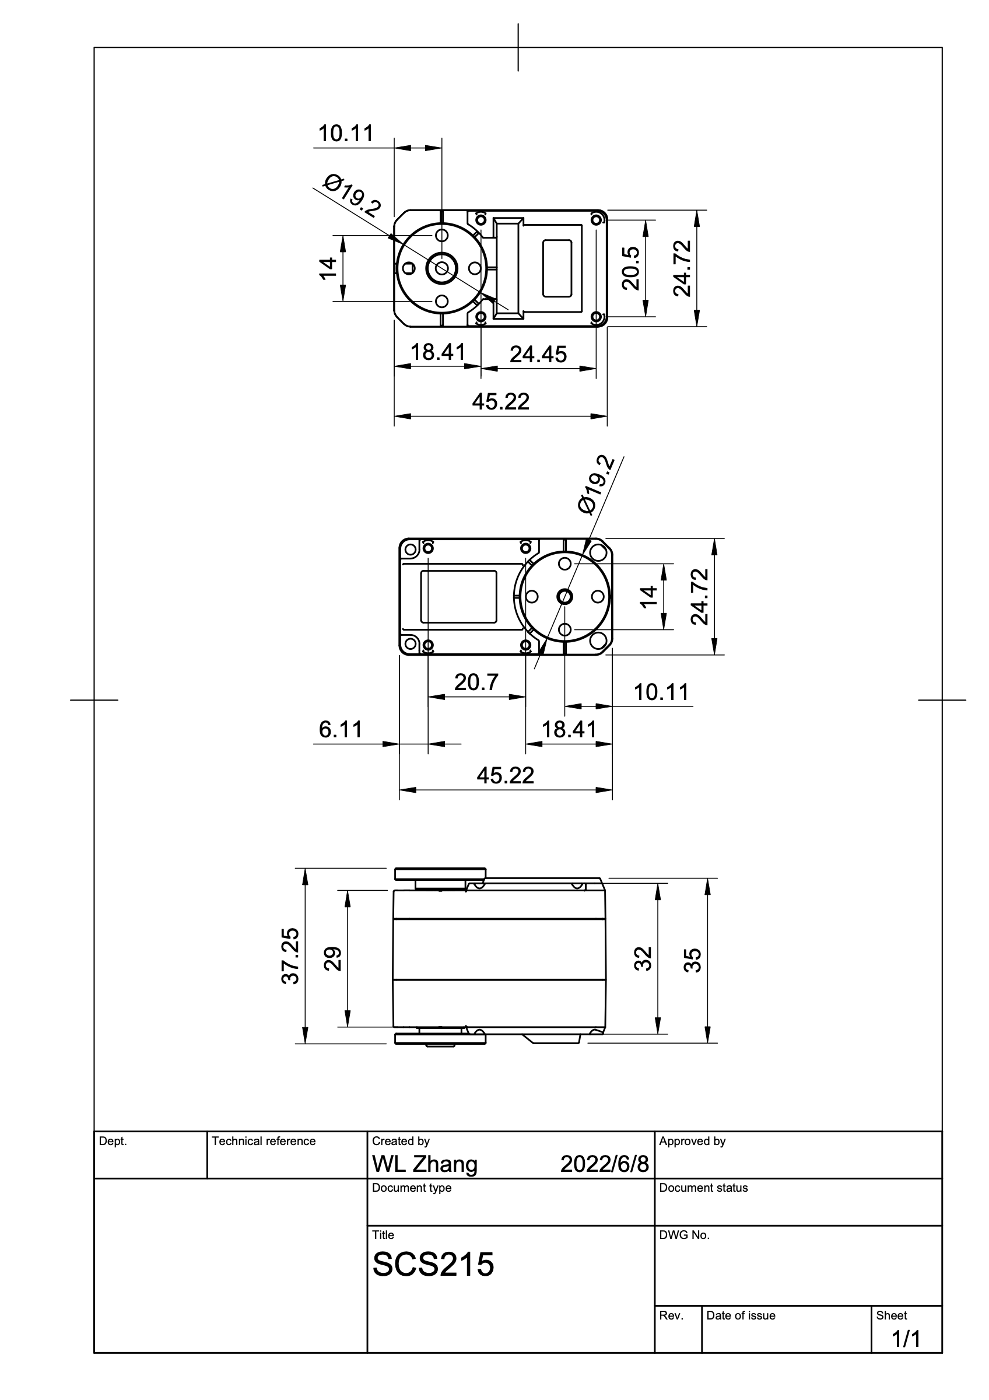
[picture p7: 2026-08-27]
3d/ref/st3215_2d.png

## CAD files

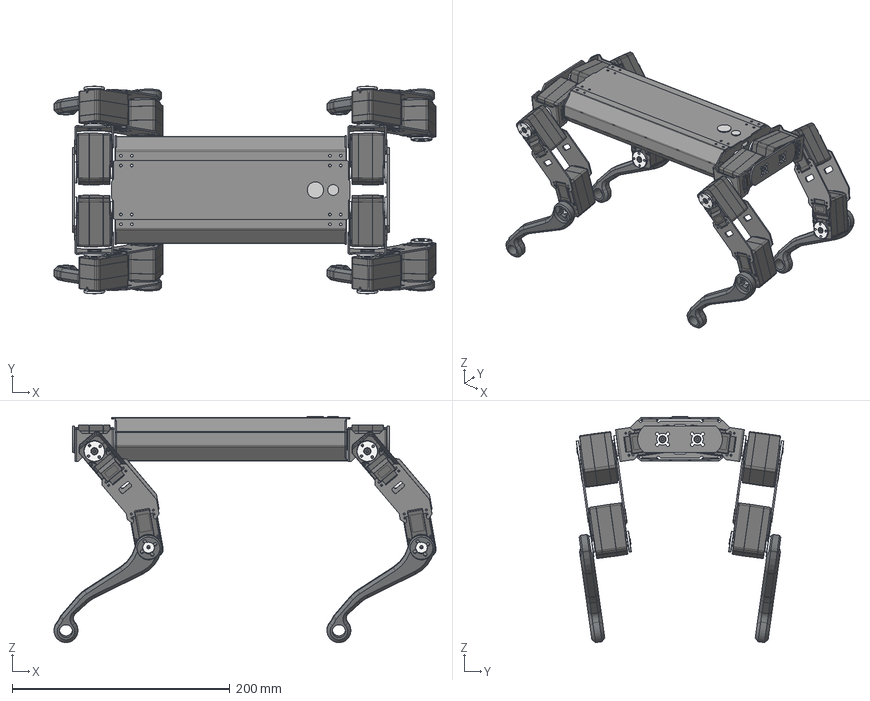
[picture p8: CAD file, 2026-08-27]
3d/ref/ROBOTIC_DOG_-STEP/ROBOTIC DOG.step
351.0 x 190.7 x 207.8 mm
前后盖板 x 2
腿部垫片 x 4
主结构 x 2
侧面板 x 2
腿部连接件 x 8
上下盖板
ZK_122 x 12
SG-ZIJI_15 x 12
XG-ZIJI_16 x 12
MOTOR-1723_3 x 12
PCB-CHAZUO_92 x 12
GE_27 x 12
金属舵盘（驱动） x 12
金属舵盘（从动） x 12
上盖板
W连接件 x 4
支架 x 4
零部件9

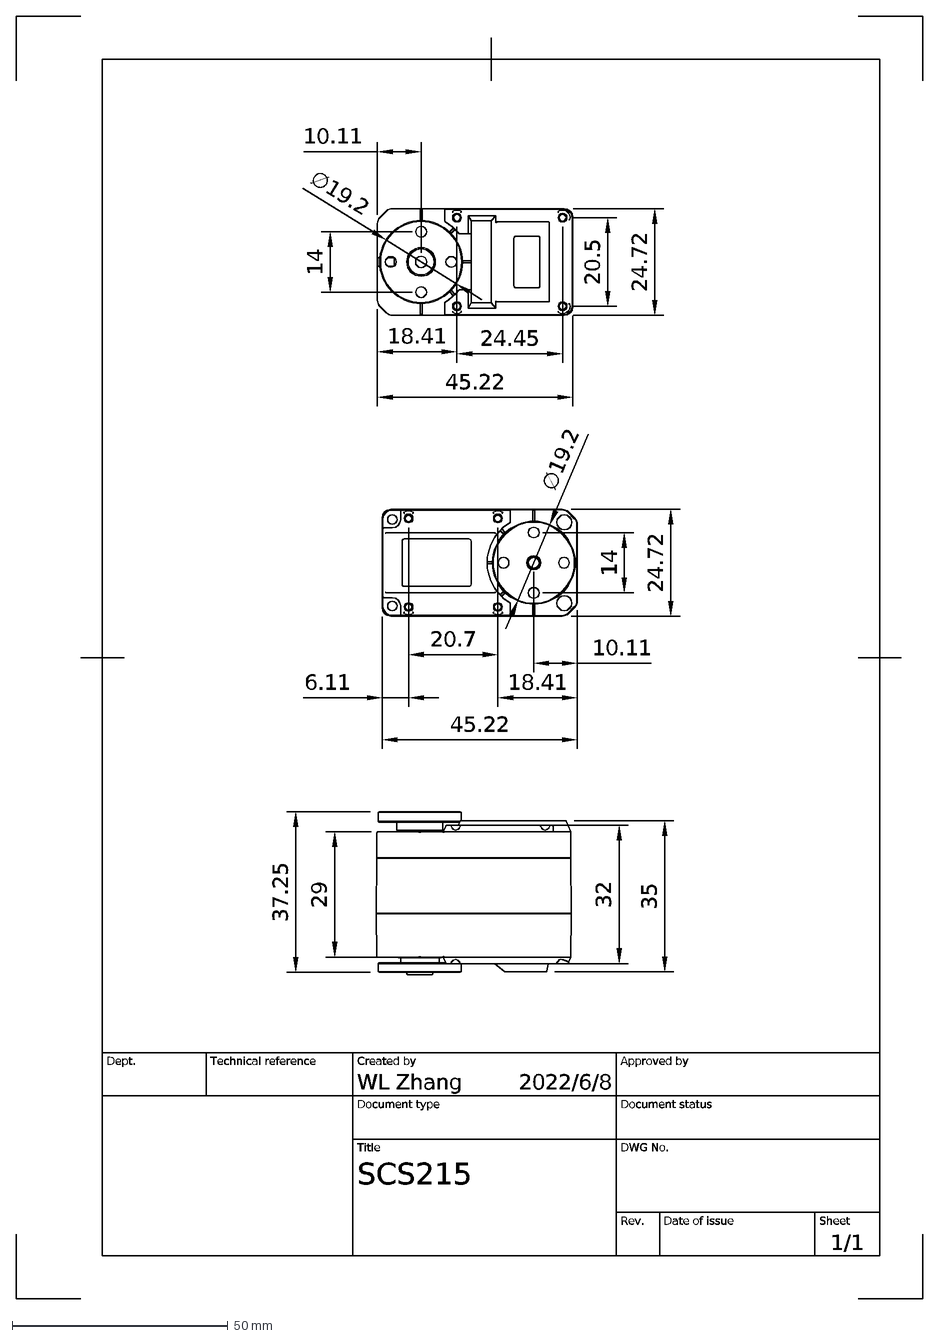
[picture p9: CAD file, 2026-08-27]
3d/ref/ST3215-2D/ST3215.dxf
2022/6/8
1/1
SCS215
WL Zhang
Dept.
Technical reference
Created by
Approved by
Document type
Document status
Title
DWG No.
Rev.
Date of issue
Sheet
24.45
18.41
10.11
20.5
24.72
45.22
37.25
20.7
6.11
∅19.2
14
32
35
29

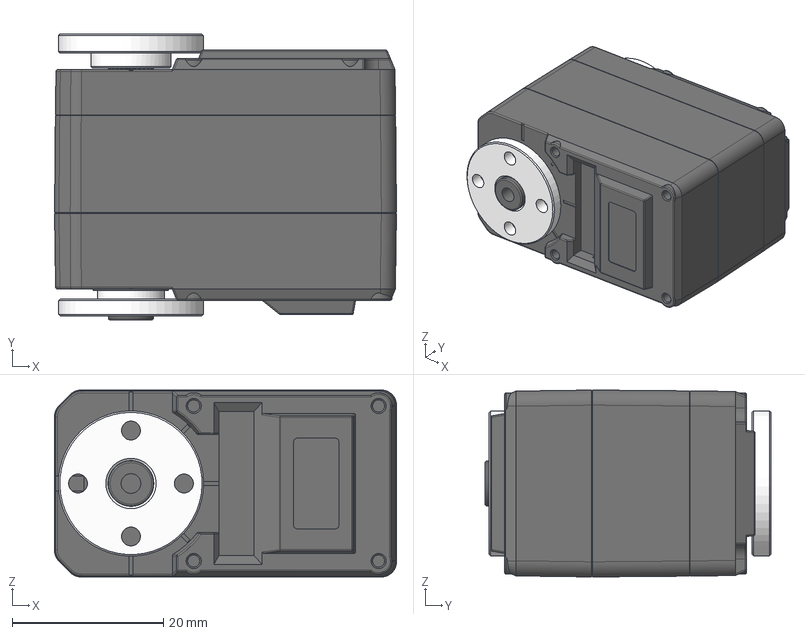
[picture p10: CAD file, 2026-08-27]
3d/ref/ST3215-3D/ST3215.step
45.2 x 37.8 x 24.7 mm
ZK_122
SG-ZIJI_15
XG-ZIJI_16
MOTOR-1723_3
PCB-CHAZUO_92
GE_27
金属舵盘（驱动）
金属舵盘（从动）

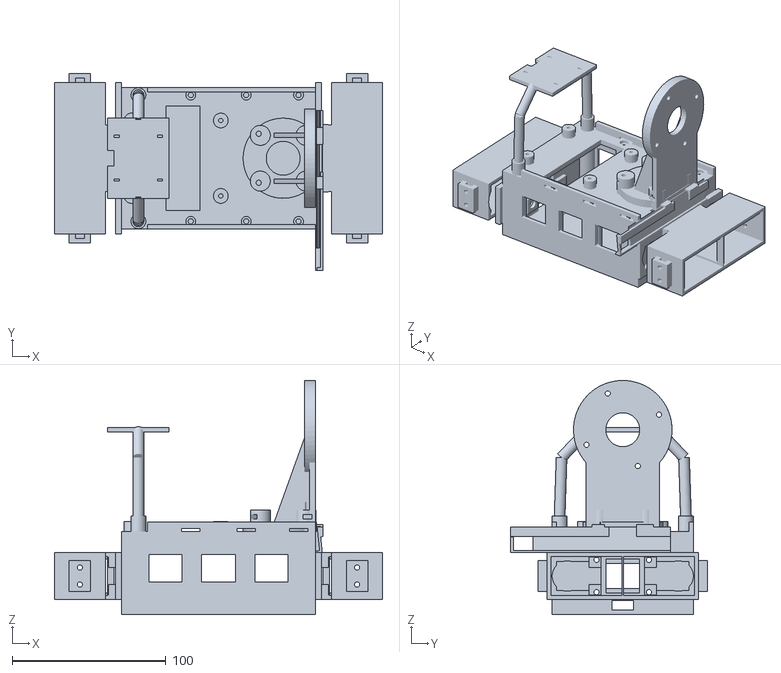
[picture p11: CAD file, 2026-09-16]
ros2/smalldog_description/meshes/base_link.stl
213.0 x 128.1 x 152.0

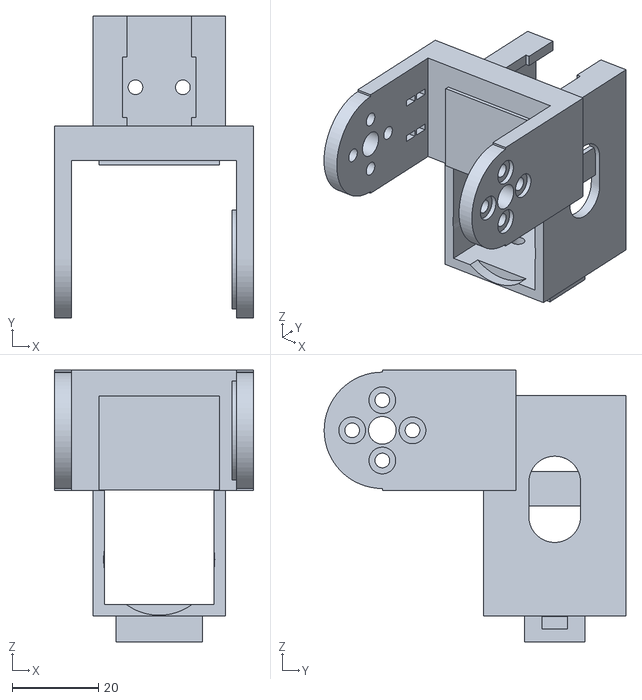
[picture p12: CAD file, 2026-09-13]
ros2/smalldog_description/meshes/rl_hip.stl
46.2 x 70.0 x 63.1

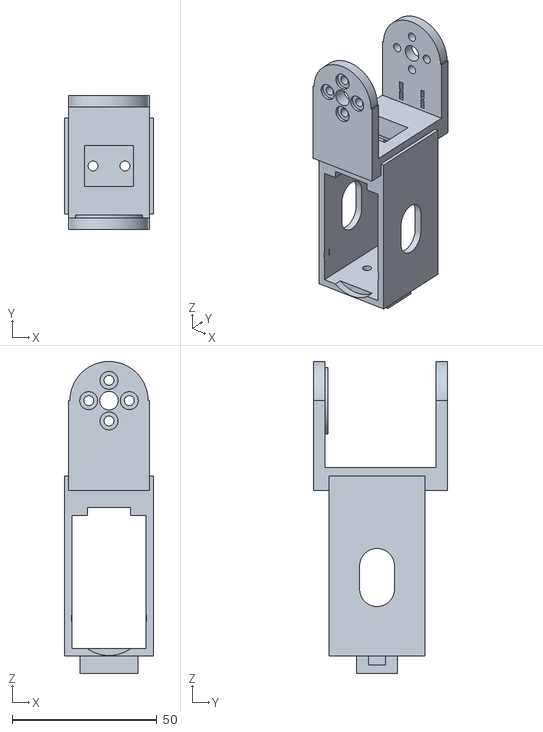
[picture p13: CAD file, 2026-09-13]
ros2/smalldog_description/meshes/fl_thigh.stl
30.7 x 46.2 x 107.6

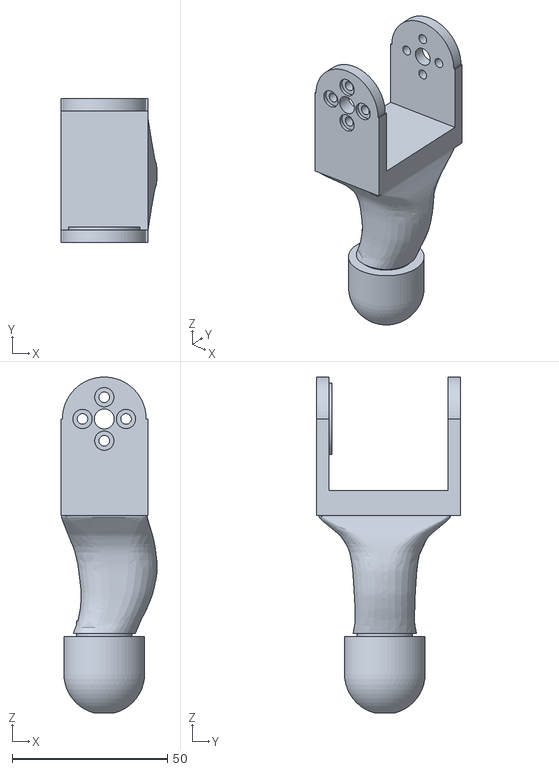
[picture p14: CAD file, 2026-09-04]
ros2/smalldog_description/meshes/rl_shin.stl
31.0 x 46.2 x 108.1

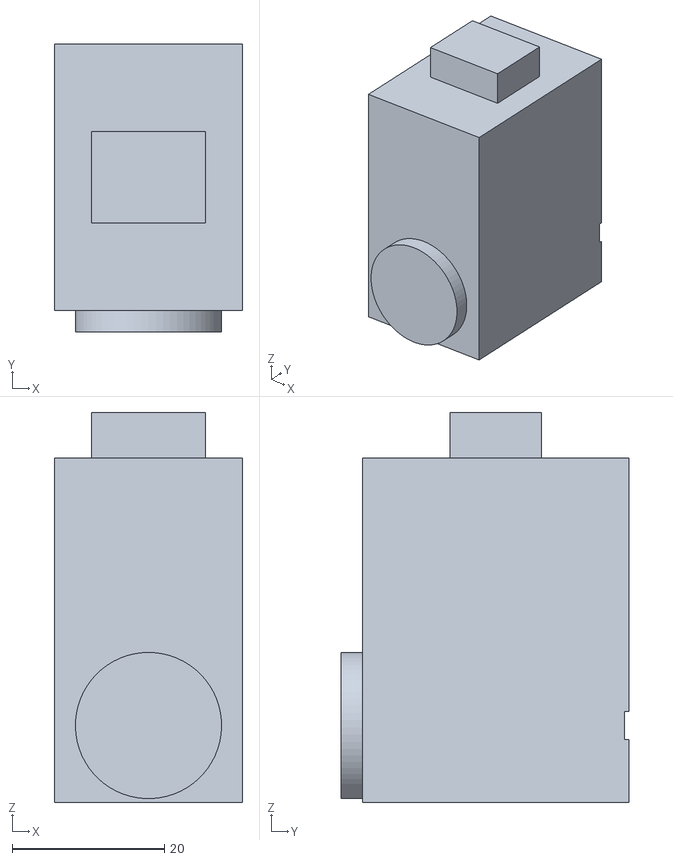
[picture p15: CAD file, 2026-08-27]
ros2/smalldog_description/meshes/fr_pitch_servo.stl
24.7 x 37.8 x 51.2

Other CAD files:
ros2/smalldog_description/meshes/fr_hip.stl
ros2/smalldog_description/meshes/rl_thigh.stl
ros2/smalldog_description/meshes/rr_hip.stl
ros2/smalldog_description/meshes/rr_thigh.stl
ros2/smalldog_description/meshes/fl_hip.stl
ros2/smalldog_description/meshes/fr_thigh.stl
ros2/smalldog_description/meshes/fl_shin.stl
ros2/smalldog_description/meshes/rr_shin.stl
ros2/smalldog_description/meshes/fr_shin.stl
ros2/smalldog_description/meshes/fl_roll_servo.stl
ros2/smalldog_description/meshes/fl_knee_servo.stl
ros2/smalldog_description/meshes/fl_pitch_servo.stl
ros2/smalldog_description/meshes/fr_knee_servo.stl
ros2/smalldog_description/meshes/fr_roll_servo.stl
ros2/smalldog_description/meshes/rl_knee_servo.stl
ros2/smalldog_description/meshes/rl_pitch_servo.stl
ros2/smalldog_description/meshes/rl_roll_servo.stl
ros2/smalldog_description/meshes/rr_knee_servo.stl
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

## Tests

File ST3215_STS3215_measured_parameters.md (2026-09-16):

# Feetech / Waveshare ST3215 (STS3215) — measured parameters

Bench measurements of a real **ST3215** serial-bus servo, 12 V, 1:345 gearbox, the
30 kg·cm variant. Published so that the next person does not have to buy the servo and
build a test stand to find out that the datasheet is optimistic in some places, silent in
others, and that one register does not mean what it looks like it means.

**Measured 2026-09-08. One servo, one sample.** Nothing here is a datasheet value unless
it says so. Where a number disagrees with the vendor's, both are given.

Search terms, so this page is findable: *ST3215 parameters, STS3215 parameters, ST3215
torque constant, ST3215 armature inertia, ST3215 friction, ST3215 present current wrong,
STS3215 PRESENT_CURRENT register 69, ST3215 MuJoCo armature damping frictionloss, ST3215
system identification, ST3215 backlash, SO-100 SO-101 STS3215 servo model, LeRobot servo
parameters, ST3215 gearbox efficiency.*

---

## TL;DR — the table

All values are **at the output shaft** (i.e. after the 1:345 reduction), SI units.

| quantity | measured | vendor / prior | how |
|---|---|---|---|
| Terminal resistance `R` | **≈ 4.0 Ω** (3.84 – 4.4) | 4.44 (12 V ÷ 2.7 A) | four routes, below |
| Torque constant `k_t` | **2.39 N·m/A** — *see the warning below* | 1.09 (2.94 N·m ÷ 2.7 A) | friction-cancelled paired holds |
| Back-EMF constant `k_e` | **2.13 V·s/rad** | 2.55 (12 ÷ 4.71) | blocked-output stall, across speeds |
| No-load speed | **5.64 rad/s @ 12 V** | 4.71 | derived from `k_e` |
| **Gearbox efficiency η** | *withdrawn* — it is `k_t/k_e` and `k_t` is flagged | 0.43 (implied by the 3 specs) | see the warning |
| Reflected inertia `J_m` | **0.0165 kg·m²** | 0.008 was a guess | free swing, at the corrected `τ_c` |
| Coulomb friction `τ_c` | **0.18 N·m** | — | two ladders + free swing, agreeing |
| Viscous friction `b_v` | **0.06 ± 0.07 N·m·s/rad** — *unresolved* | — | speed ladder minus back-EMF |
| Total speed-proportional torque | **1.37 N·m·s/rad** (`b_v + k_t·k_e`) | — | speed ladder, 3 voltages |
| Static breakaway `τ_s` | **0.23 – 0.35 N·m** | — | bracketed, hold + release |
| Load-dependent friction | **+0.28 N·m per N·m carried** | not modelled anywhere | bidirectional hold ladder |
| Back-driving loss | **≈ 62 %** of applied torque | — | free-swing energy balance |
| Position-loop stiffness | **40.9 N·m/rad @ 12 V**<br>**34.4 @ 10 V, 28.1 @ 8 V** | — | droop, friction cancelled |
| Backlash | **0.50°** at the output | ≤ 0.5° | reversal hysteresis |
| Position dead zone | **0.36°** | `CW_DEAD`/`CCW_DEAD` = 1 count | reversal |

Control registers every number above is conditional on — a fit is only valid for the gains
the servo had at the time:

```
P_COEF 32   D_COEF 32   I_COEF 0   MODE 0 (position)   ACCELERATION 0
CW_DEAD 1   CCW_DEAD 1  STARTUP_FORCE 16   TORQUE_LIMIT 1000   MAX_TORQUE 1000
PROTECTION_CURRENT 310  OVERLOAD_TORQUE 80  PROTECTIVE_TORQUE 20  OFFSET 85
```

> ### ⚠ SETTLED 2026-09-10 by a scale: the stall is **4.50 N·m**, and both of the
> figures below are wrong — in opposite directions
>
> A blocked output pressing an M6 anvil onto a 2 kg scale at a 170 mm arm, three
> duty rungs at 12 V: **k_u = 0.400 N·m/V, stall 4.50 N·m at 12 V** (4.38 read
> warm), friction intercept **−0.30 N·m**, residuals ±0.05 N·m. The answer is
> *between* the register routes' 7.4 and the datasheet's 2.94, which means the
> framing below was wrong: there was never one mis-scaling to find. The register
> channel is high by **1.64×**, not 2.2×, and the datasheet is optimistic by
> **1.53×** on top of that. The −0.30 N·m intercept is a third independent read on
> `τ_c`, against the ladder's 0.43.
>
> `k_t` and `R` are still **not** resolved: fitting (current, torque) gives a
> +0.60 N·m intercept — torque at zero current — so `PRESENT_CURRENT` remains
> unusable below ~0.2 A and the shunt is still worth doing.
>
> **Two traps if you repeat this.** A scale under a short burst reads the arm's
> inertia and its own filter ringing on top of the static force — a roughly
> *constant* offset, measured at ~130 g (920 g in 0.8 s bursts against 780 g held
> at the same duty), so it corrupts the slope as well as the level. Hold for
> several seconds and read it settled. And the torque **decays 4–7 % over an 8 s
> hold**: at fixed duty the driver sets voltage, so as the winding warms `R` rises
> and the current falls with it (~17 °C of winding rise while the case moves 1 °C).
> "Stall torque" is not one number — the cold value is what a leg gets in a
> transient, and it is the 4.50 above.
>
> **2026-09-12, full duty, and it is three numbers.** Supply dropped to 8 V so cap
> 1000 fits under the 2 kg scale, second unit, 5 s holds, protections disabled for
> the two top rungs and restored: torque is **0.40 N·m/V of drive up to ~5.5 V and
> ~0.20 N·m/V above it** (2.25 N·m at d·U 7.8 V; the same d·U reads the same at 12 V,
> so it is the motor's current, not the supply), which puts full duty at 12 V near
> **3.2 N·m cold**, not 4.50 — the 4.50 was a straight line through rungs that were
> all below the knee. And the stock protections bound what a leg can *hold*:
> `OVERLOAD_TORQUE` 80 cuts any duty above 80 % to 20 % after `PROTECTION_TIME` 2 s,
> and `PROTECTION_CURRENT` 310 × 6.5 mA = **2.0 A** cuts torque to zero — 2.0 A
> through ~4 Ω is 8 V of drive, so the **sustained stall is ~2.3 N·m at any pack
> voltage**. Warm (+7 °C case) the same rung reads 8 % less. A 3 kg scale at 12 V
> would confirm the peak; the sustained number needs nothing more.
>
> The original analysis is kept below because it is what justified building the rig.
>
> #### (superseded) The torque constant does not reconcile with the datasheet, by 2.2×
>
> Measuring it properly made it worse, which is why it is flagged rather than
> quietly averaged. Cancelling friction with the bidirectional hold ladder — the
> right way to measure a torque constant, since friction otherwise helps hold the
> arm and reads as extra motor torque — gives **2.39 N·m/A through the current
> channel and 2.38 through the duty channel**. Those agree with each other to
> 0.3 %, and imply a stall of **7.4 N·m at 12 V** against the vendor's 2.94.
>
> The servo does not produce 7.4 N·m. Something between the registers and N·m is
> mis-scaled by about 2.2×, and the two candidates are both listed under "What is
> NOT measured here": `PRESENT_CURRENT`'s 6.5 mA LSB, which has only ever been
> confirmed against vendor numbers, and `PRESENT_LOAD`'s per-mille scaling, if
> 1000 is not 100 % duty. An external shunt or an INA226 settles it and would pin
> `R`, `k_t` and the efficiency at once. *(A scale settled the stall without one;
> the shunt is still what would pin `k_t` and `R`.)*
>
> **What this does and does not contaminate.** Every friction number in this
> document is a RATIO between two quantities in the same register units,
> converted to N·m through `m·g·r`, which is known exactly — so a constant scale
> error cancels out of `τ_c`, `μ_load` and the speed-proportional total, and they
> stand. `k_t`, `R`, `k_e`, the efficiency and any stall figure derived from them
> do not. Do not size a joint off the 7.4 — or off the vendor's 2.94. Use ~3.2 for a
> transient under 2 s and ~2.3 for anything held (the block above).

---

## The one that will cost you a day: `PRESENT_CURRENT` is **supply** current

Register **69 (0x45)**, LSB **6.5 mA** — both as documented. What is *not* documented is
that it reports the current drawn from the **bus supply**, not the current through the
motor. Behind a PWM half-bridge those differ by the duty cycle, and at the low duties a
servo actually holds at, they differ by a lot.

Holding **0.865 N·m**, this servo reported **0.084 A**. A motor making that torque carries
about **0.5 A**. It looks like a broken sensor. It is not:

```
I_motor    = d · U / R           (a PWM'd brushed motor at duty d)
I_reported = d · I_motor = d² · U / R
```

so

```
    I_motor = PRESENT_CURRENT / d              d = PRESENT_LOAD / 1000
    R       = d² · U / PRESENT_CURRENT
```

**The proof.** Invert it over a ladder of holding angles — duty from `PRESENT_LOAD`,
seven points across a 7× range of duty — and it returns a constant it was never told:

| supply | `R` recovered | spread |
|---|---|---|
| 12.10 V | **4.31 Ω** | 4.29 / 4.29 / 4.29 / 4.44 / 4.36 / 4.33 |
| 10.09 V | **4.41 Ω** | 4.01 … 4.87 |

against the 4.44 Ω the vendor's locked-rotor spec implies. Two supplies 20 % apart agree
to 2 %. The `d²` law is right.

Three further routes, all agreeing, none of which knew the others' answer:

| route | `R` |
|---|---|
| Blocked output at full duty (`w` = 0, so `I = U/R` exactly) | **4.0 / 4.1 Ω** at 8 and 10 V |
| Regression over 20 936 stationary samples at any duty | **3.98 Ω** |
| Regression over 374 genuinely saturated samples | **3.84 Ω** |

**Consequences for anyone fitting a model to this servo:**

- Regressing torque against this register raw regresses against `d²` instead of `d`. It
  will not converge, and it will not tell you why — you get an unphysical non-zero-torque
  intercept at zero current.
- Divide by duty first, and both `R` and `k_t` land within 8 % of the vendor's numbers.
- The 6.5 mA LSB is **correct**. The bug is in interpretation, not scaling.

---

## Electrical

`R` and `k_t` above. The efficiency is the interesting one.

For any DC motor `k_t` [N·m/A] and `k_e` [V·s/rad] are the same number. Through a gearbox
they are not: `k_e` at the output is `n·k_e,motor` but `k_t` at the output is
`η·n·k_t,motor`, so their ratio **is** the efficiency:

```
η = k_t / k_e = 1.12 / 2.55 = 0.44
```

The three vendor specs independently imply `η = k_u·R/k_e = 0.43`. **A 1:345 spur stack at
~43 % is genuinely that lossy** — if you have been assuming a servo delivers its stall
torque per amp, it does not.

`k_e` is measured too, from the blocked-output runs where the duty is pinned and the
current then falls with speed as `I = U/R − (k_e/R)·ω`: **2.13 V·s/rad**, against the 2.55
the vendor's no-load speed implies. Using the measured `k_e` gives η = 1.12/2.13 = **0.53**;
using the vendor's, 0.44. Somewhere in 0.44–0.53, and nowhere near 1.

**One number here is NOT trustworthy: the torque constant read off a hold ladder alone.**
Fitting these runs with a model whose friction is only `τ_c·sign(ω) + b_v·ω` returns
`k_u·R` = 1.90 N·m/A and an implied stall of **5.92 N·m — twice the spec**. That is not a
strong servo, it is the missing load-dependent friction term coming out somewhere. At a
static hold friction *helps* carry the load, so a model that cannot represent friction
growing with load has nowhere to put the surplus except the motor. If you fit this servo,
expect an inflated torque constant until you add that term.

---

## Friction — and why one number is not enough

Every number below comes from a **difference between two runs of the same trajectory**,
not from a fit. That matters more than it sounds: a static hold does not settle at zero
net torque, it settles wherever friction happens to balance the rest, so the duty it holds
depends on which side the joint arrived from. Walk a ladder of angles once and every rung
sits somewhere inside that band with nothing in the log to say where; walk it up and then
down and half the difference *is* the friction while the mean is the torque without it.
The same trick on a triangle at five periods gives the speed dependence. Both ladders are
in `robot/bench/sweep.py` as `holdbi` and `speed`, and `robot/bench/hysteresis.py` prints
the table below from the raw CSVs in one command.

| | 8 V | 10 V | 12 V |
|---|---|---|---|
| effective torque constant, N·m per volt of motor drive | 0.636 | 0.611 | 0.596 |
| friction mobilised at a hold, unloaded, N·m | 0.192 | 0.181 | 0.186 |
| **…per N·m of load carried** | **0.286** | **0.295** | **0.251** |
| kinetic Coulomb extrapolated to zero load, N·m | 0.161 | 0.160 | 0.168 |
| total speed-proportional torque, N·m·s/rad | 1.403 | 1.364 | 1.334 |

The right-hand four rows are friction and a torque constant, so they **must not** move with
supply voltage, and they do not — 5–16 % across a 1.5× range, which is the error bar on the
whole method. That invariance is the check that these are physical quantities and not
artefacts of the loop.

**Coulomb `τ_c` ≈ 0.16 – 0.19 N·m**, and that is about **twice** what indirect methods give.
The two ladders agree with each other closely — 0.187 N·m from the static band, 0.163 from
the moving one — while a free-swing energy balance, a one-directional hold intercept and a
full trajectory fit all land at 0.08–0.09. The direct measurement is the one to believe:
each of the indirect three has somewhere else to put friction (`k_u`, `b_v`, the inertia)
and the differential measurement does not. The older numbers are kept below for anyone
comparing methods rather than servos.

| method | `τ_c` | direct? |
|---|---|---|
| Bidirectional hold ladder, three voltages | **0.187** | yes |
| Speed ladder intercept, three voltages | **0.163** | yes |
| Release acceleration at ω = 0, two arms | 0.125 | partly |
| Energy balance over two free swings | 0.086 | no |
| Hold-ladder intercept, one approach only | 0.079 (12 V), 0.070 (10 V) | no |
| Full trajectory fit | 0.085 | no |

**Load-dependent friction — the term most models are missing, now measured rather than
inferred.** Friction grows with the torque being transmitted, as gear-tooth normal forces
do: **+0.28 N·m per N·m carried**, on top of the 0.19 N·m floor, so at the 0.88 N·m the
long arm asks for, friction is 0.43 N·m — half the load again. This supersedes the
"+38 % of motor torque" that earlier editions of this document inferred from a
torque-vs-duty slope ratio; that route reads a one-directional ladder, which is exactly
the measurement the approach direction contaminates. Expressed against motor torque
instead of load it is about +22 %, so the direction of the correction is downward.

**Stiction is separate and larger**: 0.23–0.35 N·m breakaway. Note that the 0.19 N·m above
is not the same number and is not in conflict with it — a hold settles as soon as friction
balances, so what it mobilises is bounded by breakaway rather than equal to it.
Consequences you will meet:

- With a 1 kg mass on a 45 mm arm the servo holds anywhere in a **±14° band** around
  vertical, torque off. *Where it comes to rest is not where it hangs* — do not calibrate a
  zero from it.
- Small commanded corrections below the breakaway do not move the joint at all.

**Viscous friction `b_v` is NOT resolved here, and no amount of bench time on this rig will
resolve it.** What the speed ladder measures cleanly is the *total* torque proportional to
speed — **1.37 N·m·s/rad**, to 5 % across three voltages. That total is `b_v + k_t·k_e`, and
back-EMF alone accounts for 1.31 of it (`k_e` = 2.13 × `k_t_eff` = 0.614), leaving
**0.06 ± 0.07** for viscous friction: consistent with zero, and consistent with the 0.09–0.115
the free swings imply. The reason is structural rather than a shortage of data — back-EMF
and viscous friction each cost a motor voltage proportional to ω, and **neither depends on
supply**, so the three-voltage sweep that separates every other electrical term does nothing
at all here. Splitting them needs the motor current, and `PRESENT_CURRENT` gives that only
as `d²·U/R` at a 6.5 mA LSB. **Use the total.** For a simulator it is the total that sets
how the joint resists being moved, and putting all of it in one term or the other changes
nothing a walking robot can feel.

**Back-driving is asymmetric**: the free swing, arm falling under gravity, loses **~62 %** of
the applied torque, against ~28 % forward-driving. Both are the same 1:345 stack; a single
`τ_c·sign(ω) + b_v·ω` law cannot express either that or the load dependence above.

---

## Mechanical

**Reflected inertia `J_m` = 0.0165 kg·m²** at the output. This is the number to put in
MuJoCo's `armature`. Common priors of 0.008 are **2× too low**.

**This value replaces the 0.028–0.042 earlier editions gave, and the reason is a lesson
about the measurement rather than a refinement of it.** A free swing gives
`J = (m·g·r·sin q₀ − τ_c)/α` — the driving torque is gravity *minus friction* — so `J_m`
inherits every error in `τ_c` amplified by the ratio of the two. When the bidirectional
ladder put `τ_c` at 0.18 instead of 0.08, the driving torque nearly halved and `J_m` came
down with it. The old range was not measured against a wrong servo; it was measured
against a friction estimate half the real size. Anyone quoting a free-swing inertia should
say which `τ_c` it was computed against.

Sanity check for how dominant this is: at 1:345 the reflected rotor inertia is **~73×** a
typical small link's own inertia. In a legged robot it, not the leg, sets the joint
dynamics.

**Backlash 0.50°** at the output (0.0087 rad), from hysteresis at a loaded reversal.
Matches the vendor's "≤ 0.5°".

**The encoder sits AFTER the gearbox.** Torque off, rock the horn against the play, and
`PRESENT_POSITION` moves. This is worth knowing before you model the servo: the position
you read over the bus is the *true output angle*, so the backlash is a hole in the torque
path and not in the measurement — a controller can see its own play. It also confirms the
vendor's "360° magnetic encoder, 360/4096", which only makes sense with the sensor on the
output shaft. Thirty seconds to check, and it changes how you wire up observations.

---

## Control loop

The servo runs its own position loop; you are configuring it, not replacing it.

**Steady-state stiffness scales with supply voltage:**

| supply | stiffness | droop |
|---|---|---|
| 12 V | 40.9 N·m/rad | 1.40 °/N·m |
| 10 V | 34.4 N·m/rad | 1.67 °/N·m |
| 8 V | 28.1 N·m/rad | 2.04 °/N·m |

Linear in supply — 3.44 N·m/rad per volt — exactly as `duty = kp_reg·err` then
`τ = k_u·U·duty` predicts. **Your robot gets softer as its battery drains**, and a fixed
`kp` in a simulator cannot represent that. Over a 3S pack's 12.6 → 9.9 V that is a 21 %
change in stiffness with nothing else altered.

**These are ~40 % stiffer than earlier editions of this document said** (28.8 N·m/rad at
12.1 V, 24.5 at 10.1), and the older numbers were wrong rather than merely different. A
one-directional hold ladder measures the total standing offset from target and calls it
droop, but only part of that offset is elastic — the rest is the friction band, which does
not restore and is not stiffness. Approaching every angle from both sides and taking the
mean cancels the band and leaves the elastic part alone. The correction matters because it
runs the wrong way for anyone matching a simulator: the servo is stiffer *and* has more
friction than the single-approach reading suggests, and the two errors hide each other in
any test that only looks at where the joint ends up.

For anyone matching a MuJoCo `position` actuator to this servo at 12 V: `kp ≈ 41 N·m/rad`
at `P_COEF` 32, **with a friction term** — without one, 25–29 is the value that reproduces
the observed droop, and it will be too soft the moment the joint moves.

**Dead zone 0.36°** at the output.

**The goal profile: a firmware acceleration ceiling of 7.7 rad/s², and `ACCELERATION` 0
selects it.** The loop does not chase your target; it chases an internal goal that moves
toward the target under a speed cap (the 3.86 rad/s plateau) and an acceleration cap. A
step's peak speed is `2.8·√(step)` — 0.8 rad/s for a 0.1 rad step, 2.5 for 0.8 — the
triangle `√(a·d)` at `a ≈ 8`, the same on two arm inertias and at 8 / 10 / 12 V, so it is a
profile and not the motor. Its consequence is the servo's whole frequency response: a ±15°
sine passes 74 % at 1 Hz, 25 % at 2 Hz, **7 % at 5 Hz**, while the P loop alone would pass
100 % at 2 Hz. A policy trained against a model without this term learns a 5 Hz gait the
servo turns into a slow rock.

Register 41 does move it, in the documented unit of 100 counts/s² (0.153 rad/s²): ACC 10
gives 1.6 rad/s², 49 gives 7.4, 50 gives 7.7. **Every write above 50 reads back 50**, and
0 behaves as 50. So the vendor-side readings "0 = instant" and "the smaller, the slower" are
each half true: 0 is the fastest the servo will go, and that is 7.7 rad/s². There is no
register that lifts it. (Steps at ACC 0 / 10 / 49–254, two servos, 2026-09-14 and -16.)

**The way past it is MODE 2 (open-loop PWM) with the position loop on the host.** The
bridge has no profile: a free horn reaches its steady speed in ~70 ms from rest. A host
loop at 250 Hz over one servo (`duty = kp·err − kd·ω + kff·ω_target`, kp 9000 duty/rad
≈ 41 N·m/rad — the firmware's own stiffness — kd 150, kff 200, duty ±1000) passed a ±15°
sine at **0.99 / 0.97 / 0.95 / 0.62** at 1 / 2 / 3 / 5 Hz with 6 / 12 / 17 / 72° of lag,
against the firmware's 0.74 / 0.25 / – / 0.07. The 0.62 at 5 Hz is the motor's speed
ceiling (8.2 rad/s asked, 4.7 available), not the loop. A 0.1 rad step reaches 2.9 rad/s
(≈ 80 rad/s² against the profile's 7.7); standing error 0.05°.

What it costs: the register current peaks at 3.8 A (≈ 2.3 A real) on the 5 Hz sine, and
**the load-based overload protection is off in MODE 2** — 5 s at duty 1000 with the load
register at 100 % and `PROTECTION_TIME` 2 s tripped nothing on a free horn — **but the
current-based one still acts**: stalled against a clamp at duty 1000 (12.7 V) the register
reads 3.4 A falling to 2.8 as the winding warms (≈ 2.1 → 1.7 A real), and at 2.0 s —
`OVERCURRENT_TIME` — status 32 then 8, `TORQUE_ENABLE` cleared, drive off. Torque-off and
MODE 0 clear it. So a host loop that pins a joint against something gets 2 s at stall
torque and then a dead servo; the runtime's own current limit has to fire first. Also: **`PRESENT_POSITION` is raw in
MODE 2** — the `OFFSET` register is not applied, so a centre read in position mode is off by
exactly `OFFSET`. (`robot/bench/pwm_loop.py`, `mode2_protect.py`, 2026-09-16, one servo,
11.3 V; the bus from an Orange Pi over a CH340 costs 2.0 ms per transaction whatever its
size, so a 12-servo read + write tick is ~5.5 ms.)

---

## What is NOT measured here

Stated so nobody quotes an absence as a value:

- **`k_e` independently** — no longer: open-loop duty on a free hub (`robot/bench/noload_speed.py
  --pwm`) is linear through the origin to 5.0 rad/s at 12.1 V, **k_e = 2.39 V·s/rad**. In
  position mode the same servo stops at **3.86 rad/s** (vendor 4.71), a firmware profile cap at
  2500 counts/s, not the motor — the register reads that flat number at `TORQUE_LIMIT` 800 and
  1000 alike, on both units measured.
- **Absolute current calibration** — the 6.5 mA LSB is confirmed only against vendor
  numbers, not against an external shunt or INA226. Everything scales with it.
- **Temperature dependence** — every run above sat between 30 and 32 °C. Winding
  resistance rises with temperature and this does not capture that.
- **Sample-to-sample spread** — four servos, and gearbox friction is where it is:
  stiffness, torque constant and the back-EMF total agree to 3 %, while the friction floor
  runs 0.117–0.186 N·m and the load-dependent slope 0.251–0.380 N·m per N·m, with the
  lowest floor on the unit with the highest slope (`robot/README.md`, "Unit to unit"). Four
  of twelve, at 12 V only.
- **The `b_v` / `k_e` split** — see the friction section. Only the sum is measured, and this
  is a structural limit of a bench with no external ammeter, not a gap that more runs close.
- **Why the loop runs out of authority above ~1.8 rad/s** — the duty never pins, so it is
  not the motor's ceiling. `D_COEF` is 32 and unmodelled, which would do exactly this, but
  a run that separates a derivative term from an internal output clamp has not been taken.
(The encoder question used to be listed here. It is answered — see below.)

---
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

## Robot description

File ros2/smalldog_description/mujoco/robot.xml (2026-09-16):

<mujoco model="smalldog">
  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
  <compiler angle="radian" meshdir="../meshes" autolimits="true"/>
  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
  <worldbody>
    <body name="base_link" pos="0 0 0.1807" childclass="mujoco">
      <freejoint name="base_freejoint"/>
      <inertial pos="0.010018 -0.000020 0.027242" mass="1.61533" fullinertia="0.00395508 0.00870624 0.00742800 0.00000471 -0.00112218 -0.00000087"/>
      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
      <camera name="camera" pos="0.0787343 0 0.0257543" quat="-0.473147 -0.525483 0.525483 0.473147" fovy="52.23" resolution="3840 2160"/>
      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
      <body name="fl_hip" pos="0.09000 0.03600 0.00000">
        <joint name="fl_roll" axis="1 0 0" range="-1.5408 1.5408"/>
        <inertial pos="0.000203 0.009219 -0.015260" mass="0.09005" fullinertia="0.00005179 0.00003278 0.00004057 -0.00000026 -0.00000028 0.00000064"/>
        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
        <body name="fl_thigh" pos="0.00000 0.04000 -0.03000">
          <joint name="fl_pitch" axis="0 1 0" range="-1.5408 1.5408"/>
          <inertial pos="0.000016 0.000208 -0.053672" mass="0.09697" fullinertia="0.00006650 0.00005956 0.00002098 0.00000000 -0.00000002 -0.00000052"/>
          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
          <body name="fl_shin" pos="0.00000 0.00000 -0.07500">
            <joint name="fl_knee" axis="0 1 0" range="-1.8899 1.8899"/>
            <inertial pos="-0.000765 0.000406 -0.040530" mass="0.04630" fullinertia="0.00003772 0.00003304 0.00001004 -0.00000002 -0.00000030 -0.00000038"/>
            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
          </body>
        </body>
      </body>
      <body name="fr_hip" pos="0.09000 -0.03600 0.00000">
        <joint name="fr_roll" axis="1 0 0" range="-1.5408 1.5408"/>
        <inertial pos="0.000203 -0.009219 -0.015260" mass="0.09005" fullinertia="0.00005179 0.00003278 0.00004057 0.00000026 -0.00000028 -0.00000064"/>
        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
        <body name="fr_thigh" pos="0.00000 -0.04000 -0.03000">
          <joint name="fr_pitch" axis="0 1 0" range="-1.5408 1.5408"/>
          <inertial pos="0.000016 -0.000208 -0.053672" mass="0.09697" fullinertia="0.00006650 0.00005956 0.00002098 -0.00000000 -0.00000002 0.00000052"/>
          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
          <body name="fr_shin" pos="0.00000 0.00000 -0.07500">
            <joint name="fr_knee" axis="0 1 0" range="-1.8899 1.8899"/>
            <inertial pos="-0.000765 -0.000406 -0.040530" mass="0.04630" fullinertia="0.00003772 0.00003304 0.00001004 0.00000002 -0.00000030 0.00000038"/>
            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
          </body>
        </body>
      </body>
      <body name="rl_hip" pos="-0.09000 0.03600 0.00000">
        <joint name="rl_roll" axis="1 0 0" range="-1.5408 1.5408"/>
        <inertial pos="-0.000203 0.009219 -0.015260" mass="0.09005" fullinertia="0.00005179 0.00003278 0.00004057 0.00000026 0.00000028 0.00000064"/>
        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
        <body name="rl_thigh" pos="0.00000 0.04000 -0.03000">
          <joint name="rl_pitch" axis="0 1 0" range="-1.5408 1.5408"/>
          <inertial pos="-0.000016 0.000208 -0.053672" mass="0.09697" fullinertia="0.00006650 0.00005956 0.00002098 -0.00000000 0.00000002 -0.00000052"/>
          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
          <body name="rl_shin" pos="0.00000 0.00000 -0.07500">
            <joint name="rl_knee" axis="0 1 0" range="-1.8899 1.8899"/>
            <inertial pos="0.000765 0.000406 -0.040530" mass="0.04630" fullinertia="0.00003772 0.00003304 0.00001004 0.00000002 0.00000030 -0.00000038"/>
            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
          </body>
        </body>
      </body>
      <body name="rr_hip" pos="-0.09000 -0.03600 0.00000">
        <joint name="rr_roll" axis="1 0 0" range="-1.5408 1.5408"/>
        <inertial pos="-0.000203 -0.009219 -0.015260" mass="0.09005" fullinertia="0.00005179 0.00003278 0.00004057 -0.00000026 0.00000028 -0.00000064"/>
        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
        <body name="rr_thigh" pos="0.00000 -0.04000 -0.03000">
          <joint name="rr_pitch" axis="0 1 0" range="-1.5408 1.5408"/>
          <inertial pos="-0.000016 -0.000208 -0.053672" mass="0.09697" fullinertia="0.00006650 0.00005956 0.00002098 0.00000000 0.00000002 0.00000052"/>
          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
          <body name="rr_shin" pos="0.00000 0.00000 -0.07500">
            <joint name="rr_knee" axis="0 1 0" range="-1.8899 1.8899"/>
            <inertial pos="0.000765 -0.000406 -0.040530" mass="0.04630" fullinertia="0.00003772 0.00003304 0.00001004 -0.00000002 0.00000030 0.00000038"/>
            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
          </body>
        </body>
      </body>
    </body>
  </worldbody>
  <actuator>
    <position class="mujoco" name="fl_roll" joint="fl_roll"/>
    <position class="mujoco" name="fl_pitch" joint="fl_pitch"/>
    <position class="mujoco" name="fl_knee" joint="fl_knee"/>
    <position class="mujoco" name="fr_roll" joint="fr_roll"/>
    <position class="mujoco" name="fr_pitch" joint="fr_pitch"/>
    <position class="mujoco" name="fr_knee" joint="fr_knee"/>
    <position class="mujoco" name="rl_roll" joint="rl_roll"/>
    <position class="mujoco" name="rl_pitch" joint="rl_pitch"/>
    <position class="mujoco" name="rl_knee" joint="rl_knee"/>
    <position class="mujoco" name="rr_roll" joint="rr_roll"/>
    <position class="mujoco" name="rr_pitch" joint="rr_pitch"/>
    <position class="mujoco" name="rr_knee" joint="rr_knee"/>
  </actuator>
  <sensor>
    <framequat name="imu_quat" objtype="site" objname="imu"/>
    <gyro name="imu_gyro" site="imu"/>
    <accelerometer name="imu_accel" site="imu"/>
    <touch name="fl_contact" site="fl_foot_site"/>
    <touch name="fr_contact" site="fr_foot_site"/>
    <touch name="rl_contact" site="rl_foot_site"/>
    <touch name="rr_contact" site="rr_foot_site"/>
  </sensor>
  <custom>
    <numeric name="lidar_cone" data="1.67552"/>
    <numeric name="lidar_rate" data="62340"/>
    <numeric name="lidar_range" data="0.05 30"/>
    <numeric name="lidar_sigma" data="0.02"/>
    <numeric name="lidar_spin" data="215.7 4.354"/>
    <numeric name="lidar_frame_hz" data="12"/>
    <numeric name="lidar_groups" data="1 1 0 1 1 1"/>
  </custom>
</mujoco>

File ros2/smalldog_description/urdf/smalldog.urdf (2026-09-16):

<?xml version="1.0"?>
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
<robot name="smalldog">
  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
  <link name="base_link">
    <inertial>
      <origin xyz="0.010018 -0.000020 0.027242" rpy="0 0 0"/>
      <mass value="1.61533"/>
      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
    </inertial>
    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
  </link>
  <link name="fl_hip">
    <inertial>
      <origin xyz="0.000203 0.009219 -0.015260" rpy="0 0 0"/>
      <mass value="0.09005"/>
      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
    </inertial>
    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
  </link>
  <link name="fl_thigh">
    <inertial>
      <origin xyz="0.000016 0.000208 -0.053672" rpy="0 0 0"/>
      <mass value="0.09697"/>
      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
    </inertial>
    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
  </link>
  <link name="fl_shin">
    <inertial>
      <origin xyz="-0.000765 0.000406 -0.040530" rpy="0 0 0"/>
      <mass value="0.04630"/>
      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
    </inertial>
    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
  </link>
  <link name="fr_hip">
    <inertial>
      <origin xyz="0.000203 -0.009219 -0.015260" rpy="0 0 0"/>
      <mass value="0.09005"/>
      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
    </inertial>
    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
  </link>
  <link name="fr_thigh">
    <inertial>
      <origin xyz="0.000016 -0.000208 -0.053672" rpy="0 0 0"/>
      <mass value="0.09697"/>
      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
    </inertial>
    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
  </link>
  <link name="fr_shin">
    <inertial>
      <origin xyz="-0.000765 -0.000406 -0.040530" rpy="0 0 0"/>
      <mass value="0.04630"/>
      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
    </inertial>
    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
  </link>
  <link name="rl_hip">
    <inertial>
      <origin xyz="-0.000203 0.009219 -0.015260" rpy="0 0 0"/>
      <mass value="0.09005"/>
      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
    </inertial>
    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
  </link>
  <link name="rl_thigh">
    <inertial>
      <origin xyz="-0.000016 0.000208 -0.053672" rpy="0 0 0"/>
      <mass value="0.09697"/>
      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
    </inertial>
    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
  </link>
  <link name="rl_shin">
    <inertial>
      <origin xyz="0.000765 0.000406 -0.040530" rpy="0 0 0"/>
      <mass value="0.04630"/>
      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
    </inertial>
    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
  </link>
  <link name="rr_hip">
    <inertial>
      <origin xyz="-0.000203 -0.009219 -0.015260" rpy="0 0 0"/>
      <mass value="0.09005"/>
      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
    </inertial>
    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
  </link>
  <link name="rr_thigh">
    <inertial>
      <origin xyz="-0.000016 -0.000208 -0.053672" rpy="0 0 0"/>
      <mass value="0.09697"/>
      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
    </inertial>
    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
  </link>
  <link name="rr_shin">
    <inertial>
      <origin xyz="0.000765 -0.000406 -0.040530" rpy="0 0 0"/>
      <mass value="0.04630"/>
      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
    </inertial>
    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
  </link>
  <joint name="fl_roll" type="revolute">
    <parent link="base_link"/>
    <child link="fl_hip"/>
    <origin xyz="0.09000 0.03600 0.00000" rpy="0 0 0"/>
    <axis xyz="1 0 0"/>
    <limit lower="-1.5708" upper="1.5708" effort="3.2" velocity="3.86"/>
  </joint>
  <joint name="fl_pitch" type="revolute">
    <parent link="fl_hip"/>
    <child link="fl_thigh"/>
    <origin xyz="0.00000 0.04000 -0.03000" rpy="0 0 0"/>
    <axis xyz="0 1 0"/>
    <limit lower="-1.5708" upper="1.5708" effort="3.2" velocity="3.86"/>
  </joint>
  <joint name="fl_knee" type="revolute">
    <parent link="fl_thigh"/>
    <child link="fl_shin"/>
    <origin xyz="0.00000 0.00000 -0.07500" rpy="0 0 0"/>
    <axis xyz="0 1 0"/>
    <limit lower="-1.9199" upper="1.9199" effort="3.2" velocity="3.86"/>
  </joint>
  <joint name="fr_roll" type="revolute">
    <parent link="base_link"/>
    <child link="fr_hip"/>
    <origin xyz="0.09000 -0.03600 0.00000" rpy="0 0 0"/>
    <axis xyz="1 0 0"/>
    <limit lower="-1.5708" upper="1.5708" effort="3.2" velocity="3.86"/>
  </joint>
  <joint name="fr_pitch" type="revolute">
    <parent link="fr_hip"/>
    <child link="fr_thigh"/>
    <origin xyz="0.00000 -0.04000 -0.03000" rpy="0 0 0"/>
    <axis xyz="0 1 0"/>
    <limit lower="-1.5708" upper="1.5708" effort="3.2" velocity="3.86"/>
  </joint>
  <joint name="fr_knee" type="revolute">
    <parent link="fr_thigh"/>
    <child link="fr_shin"/>
    <origin xyz="0.00000 0.00000 -0.07500" rpy="0 0 0"/>
    <axis xyz="0 1 0"/>
    <limit lower="-1.9199" upper="1.9199" effort="3.2" velocity="3.86"/>
  </joint>
  <joint name="rl_roll" type="revolute">
    <parent link="base_link"/>
    <child link="rl_hip"/>
    <origin xyz="-0.09000 0.03600 0.00000" rpy="0 0 0"/>
    <axis xyz="1 0 0"/>
    <limit lower="-1.5708" upper="1.5708" effort="3.2" velocity="3.86"/>
  </joint>
  <joint name="rl_pitch" type="revolute">
    <parent link="rl_hip"/>
    <child link="rl_thigh"/>
    <origin xyz="0.00000 0.04000 -0.03000" rpy="0 0 0"/>
    <axis xyz="0 1 0"/>
    <limit lower="-1.5708" upper="1.5708" effort="3.2" velocity="3.86"/>
  </joint>
  <joint name="rl_knee" type="revolute">
    <parent link="rl_thigh"/>
    <child link="rl_shin"/>
    <origin xyz="0.00000 0.00000 -0.07500" rpy="0 0 0"/>
    <axis xyz="0 1 0"/>
    <limit lower="-1.9199" upper="1.9199" effort="3.2" velocity="3.86"/>
  </joint>
  <joint name="rr_roll" type="revolute">
    <parent link="base_link"/>
    <child link="rr_hip"/>
    <origin xyz="-0.09000 -0.03600 0.00000" rpy="0 0 0"/>
    <axis xyz="1 0 0"/>
    <limit lower="-1.5708" upper="1.5708" effort="3.2" velocity="3.86"/>
  </joint>
  <joint name="rr_pitch" type="revolute">
    <parent link="rr_hip"/>
    <child link="rr_thigh"/>
    <origin xyz="0.00000 -0.04000 -0.03000" rpy="0 0 0"/>
    <axis xyz="0 1 0"/>
    <limit lower="-1.5708" upper="1.5708" effort="3.2" velocity="3.86"/>
  </joint>
  <joint name="rr_knee" type="revolute">
    <parent link="rr_thigh"/>
    <child link="rr_shin"/>
    <origin xyz="0.00000 0.00000 -0.07500" rpy="0 0 0"/>
    <axis xyz="0 1 0"/>
    <limit lower="-1.9199" upper="1.9199" effort="3.2" velocity="3.86"/>
  </joint>
  <link name="lidar_link"/>
  <joint name="lidar_link_joint" type="fixed">
    <parent link="base_link"/><child link="lidar_link"/>
    <origin xyz="0.1075 0 0.095" rpy="0 1.5708 0"/>
  </joint>
  <link name="camera_link"/>
  <joint name="camera_joint" type="fixed">
    <parent link="base_link"/><child link="camera_link"/>
    <origin xyz="0.0787343 0 0.0257543" rpy="0 -0.10472 0"/>
  </joint>
  <link name="camera_optical_frame"/>
  <joint name="camera_optical_joint" type="fixed">
    <parent link="camera_link"/><child link="camera_optical_frame"/>
    <origin xyz="0 0 0" rpy="-1.5708 0 -1.5708"/>
  </joint>
  <link name="gps_link"/>
  <joint name="gps_joint" type="fixed">
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

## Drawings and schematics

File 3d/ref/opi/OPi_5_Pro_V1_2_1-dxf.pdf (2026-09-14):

# ART FILM - ref_bot

## C9 FB2

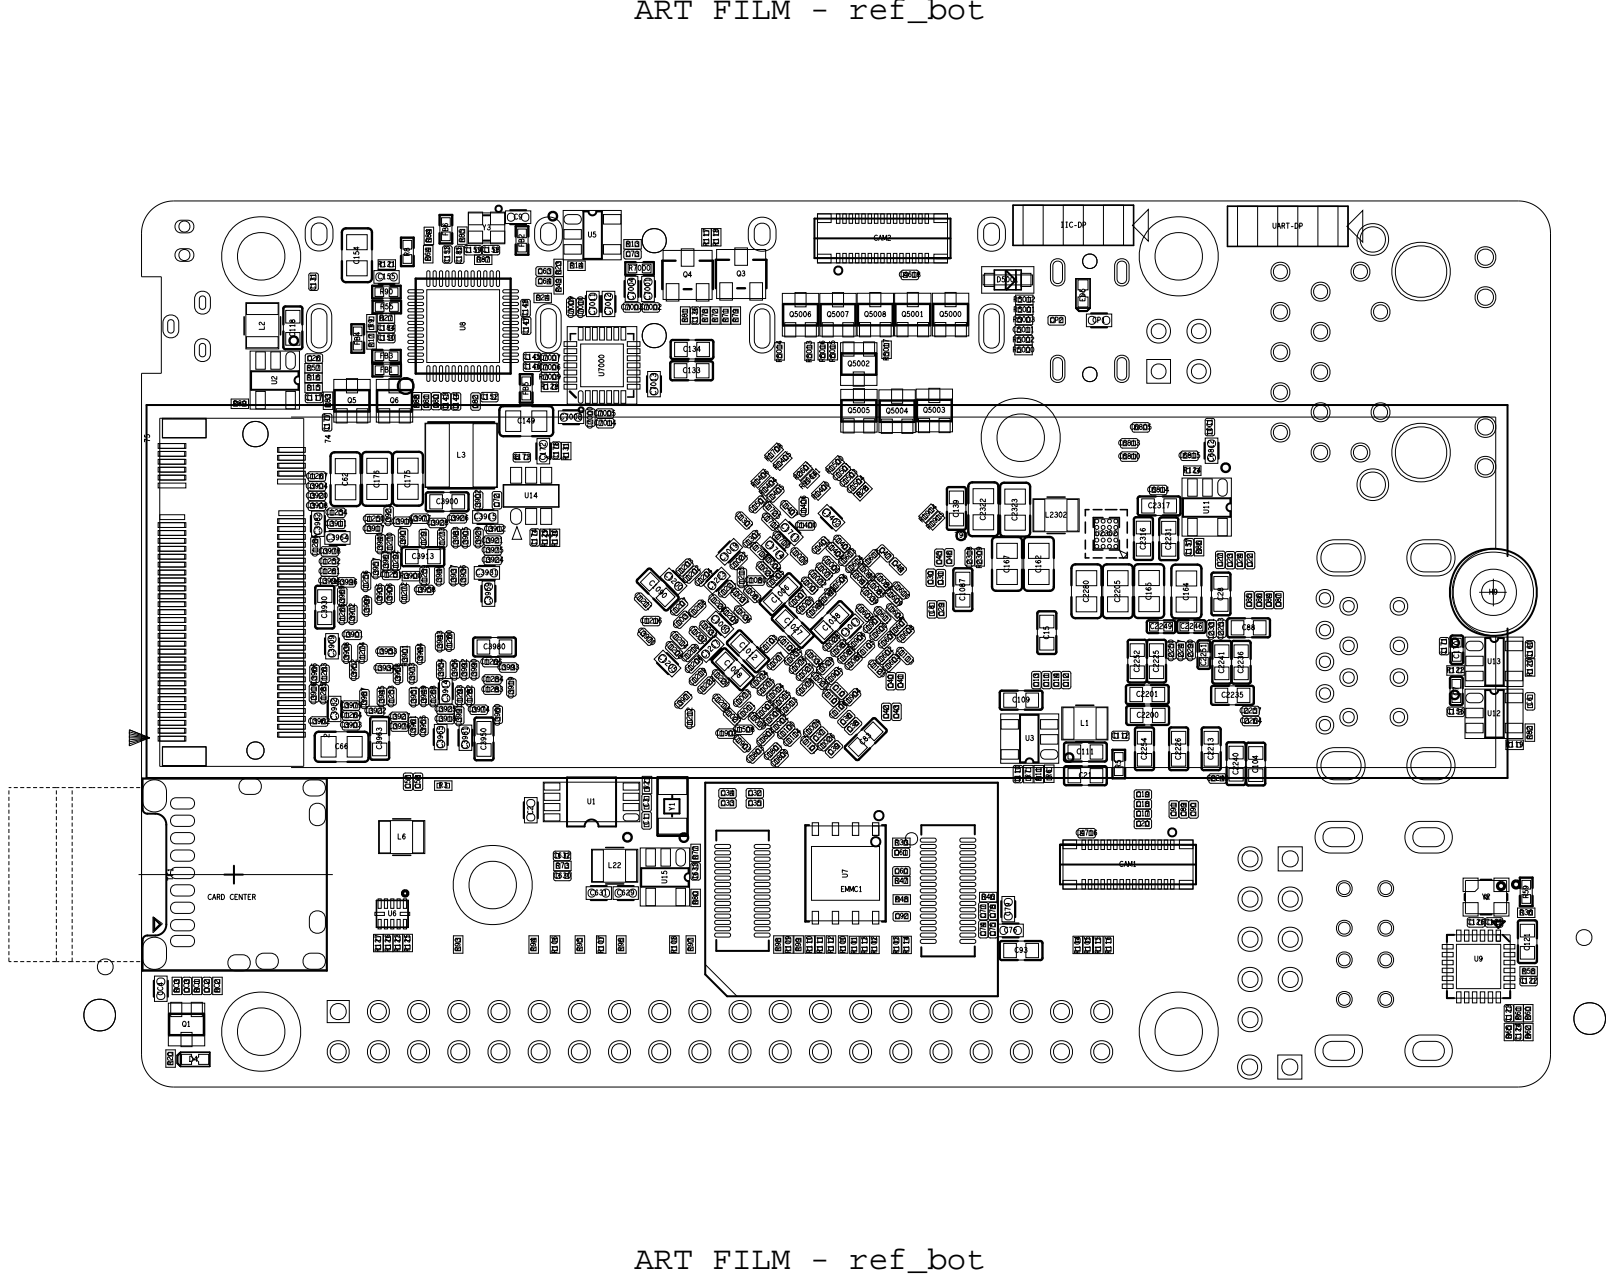
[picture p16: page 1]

# ART FILM - ref_top

58R74 R75

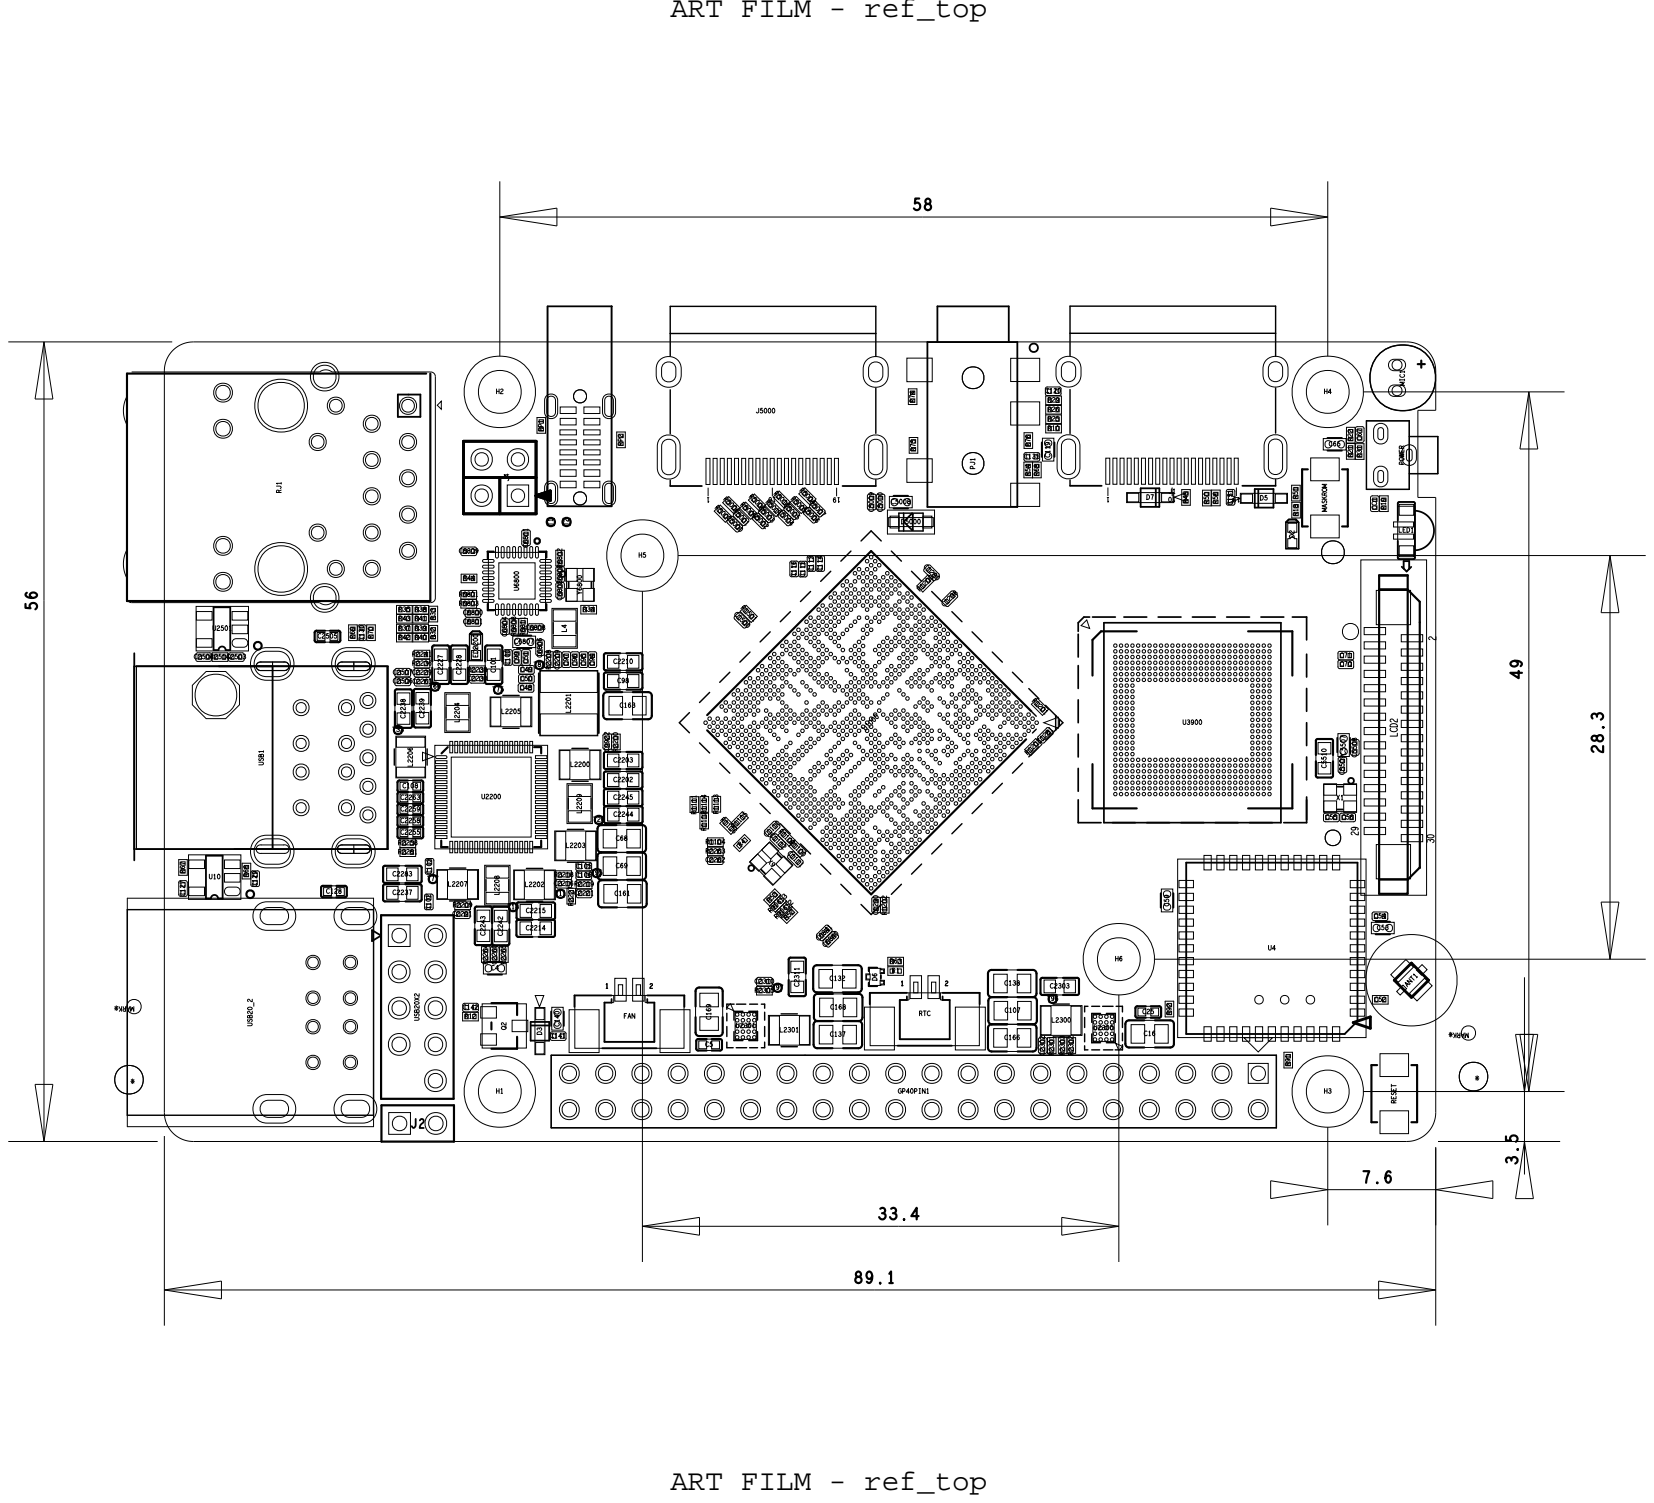
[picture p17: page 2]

GP40PIN1

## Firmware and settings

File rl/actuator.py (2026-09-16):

"""
actuator.py — the ST3215 as a voltage-driven machine, not an ideal PD.

The model, and why each term is in it
-------------------------------------
A position-mode bus servo is a closed loop we do not own: it reads its own
encoder, computes a PWM duty from its own registers, and drives a brushed motor
through a 1:345 gearbox. Everything the robot experiences — the torque ceiling
falling as the pack drains, the speed limit, the stiction near a reversal, the
dead angle at zero crossing — comes out of that chain. An ideal PD in MuJoCo
reproduces none of it, and a policy trained against one learns to spend torque
and speed the servo does not have.

So the chain is modelled as it is, in five stages:

  1. inner loop     duty = kp*err + kd*(-w), on the QUANTISED encoder reading,
                    with the servo's own dead zone and minimum-startup-force
                    ("punch") registers, saturating at +-1.
  2. voltage        U = duty * U_bat.  This is the whole point: U_bat is a 3S
                    pack under load, not a constant, so torque and no-load speed
                    fall together as it drains.
  3. electrical     i = (U - k_e*w) / R.  The back-EMF term is what makes the
                    servo's speed limit emerge instead of being clamped on.
  4. mechanical     tau = k_u*U - k_w*w - friction, driving the reflected rotor
                    inertia J_m, which for 1:345 is ~151x the knee link's own
                    inertia (measured: rl/checks/check_model.py prints the
                    ratio; it read 73x against an earlier armature). The friction
                    is (tau_c + mu_load*|tau_transmitted|)*sign(w) + b_v*w, and
                    the middle term is not a refinement: on this gearbox it is
                    0.28 N*m per N*m carried against a 0.19 N*m floor, so at the
                    bench arm's 0.88 N*m it is half the load again. Measured
                    2026-09-09; see friction() for how, and for why there is no
                    forward/back-driving asymmetry beside it.
  5. transmission   a deadzone spring of width theta_bl between motor and output.
                    Below it no torque crosses at all.

Identifiability
---------------
k_u, k_w, k_e and R are not independent — k_u = eta*k_e/R and k_w = k_u*k_e —
and from position data alone at a single voltage, the back-EMF damping k_w and
the viscous friction b_v are the same column of the regressor. They separate on
two things and only those two: measured CURRENT (which sees k_e and R but not
b_v) and runs at SEVERAL SUPPLY VOLTAGES. That is why robot/bench/sweep.py
insists on both, and why a fit from one voltage with no ammeter is refused
rather than reported with wide error bars.

**The b_v / k_e half of that is now known to be a dead end on this bench, and the
voltage sweep does not rescue it.** Both terms cost a motor voltage proportional
to omega and NEITHER depends on supply, so eight volts says exactly what twelve
does. What the speed ladder measures cleanly is their SUM, 1.37 N*m*s/rad to
5 % over three voltages, of which back-EMF is 1.31 — leaving 0.06 +- 0.07 for
b_v, i.e. consistent with zero. Use the sum. Splitting it needs a current
measurement finer than PRESENT_CURRENT's 6.5 mA LSB divided by a duty.

**The friction terms are immune to the register-scale problem below, and that is
worth knowing before trusting them.** tau_c and mu_load are measured as ratios
between two quantities in the same PRESENT_LOAD units, converted to N*m through
a gravity anchor that is known exactly, so any constant mis-scaling of that
register cancels out of both. k_u is not so lucky: friction-cancelled holds put
the torque constant at 2.39 N*m/A through the current channel and 2.38 through
the duty channel — agreeing to 0.3 % with each other and disagreeing by 2.2x
with the vendor's 1.09. See PLAN.md step 2c; it is not friction, because
removing friction makes it worse rather than better.

Where the encoder sits
----------------------
`enc_after_backlash` decides whether the servo's control loop — and the position
we read back over the bus — sees the output shaft (after the gearbox play) or
the motor side. The vendor wiki in 3d/ref/st3215_wiki.html says "360 degree
magnetic encoder ... 360/4096", i.e. one absolute turn of the OUTPUT, which only
works with the sensor on the output shaft.

**CONFIRMED on the bench, 2026-09-08: the encoder is AFTER the gearbox.** Torque
off, rocking the horn against the play moves Present Position. So the servo reads
the true joint angle, and the backlash is a hole in the TORQUE path, not in the
measurement — the robot can observe its own play. `True` below is now measured,
not inherited from a wiki. The answer changes the observation wiring in
step 4, so it is a parameter and not an assumption baked into the equations.

Units are SI at the joint: rad, rad/s, N*m, V, A.
"""
from __future__ import annotations

import dataclasses
import json
import math
import os

import numpy as np

ENC_STEPS = 4096                      # counts per output turn, vendor spec
ENC_STEP_RAD = 2.0 * math.pi / ENC_STEPS


@dataclasses.dataclass
class Params:
    """One servo's parameters. Everything here is meant to be FITTED.

    The defaults are priors derived from the vendor sheet, not measurements, and
    `fitted=False` marks them as such — `load()` says so out loud, because a
    policy trained on vendor priors and deployed on a real servo is exactly the
    failure this whole file exists to avoid.
    """
    # --- electrical -------------------------------------------------------
    # The three vendor numbers pin these exactly, and are worth doing out loud
    # because they also expose how lossy this gearbox is:
    #   locked rotor 2.7 A @ 12 V  ->  R   = 12 / 2.7   = 4.44 ohm
    #   no load 4.71 rad/s @ 12 V  ->  k_e = 12 / 4.71  = 2.55 V*s/rad
    #       (MEASURED: 3.86 on the free hub, and it is a PLATEAU of the
    #        position loop's profile at 2500 counts/s - open loop the motor
    #        runs to 5.0 rad/s, k_e = 2.39.  The law has no such cap; what it
    #        needs is a rate cap on the GOAL, a state per joint.  PLAN.md 3c.)
    #   stall 2.94 N*m @ 12 V      ->  k_u = 2.94 / 12  = 0.245 N*m/V
    # and then eta = k_u*R/k_e = 0.43. A 43 %-efficient drivetrain is low even
    # for a 1:345 stack of spur gears; either the gearbox really is that lossy
    # or one of the three specs is optimistic. Both possibilities are reasons to
    # fit rather than compute, which is what this file is for.
    R: float = 4.44           # ohm, motor + wiring, at the terminals
    k_e: float = 2.55         # V*s/rad at the JOINT (= n*kt)
    k_u: float = 0.245        # N*m per volt at zero speed (= eta*n*kt/R)
    # --- mechanical -------------------------------------------------------
    J_m: float = 0.008        # kg*m^2, reflected rotor+gearbox inertia at the joint
    J_l: float = 0.0          # kg*m^2, load-side inertia the servo carries itself
    tau_c: float = 0.05       # N*m, Coulomb friction at zero load
    b_v: float = 0.010        # N*m*s/rad, viscous friction
    # Friction that GROWS WITH THE TORQUE BEING TRANSMITTED, as gear-tooth
    # normal forces do.  N*m of friction per N*m through the gearbox.  Unlike
    # its neighbours this default is a MEASUREMENT, not a vendor prior: the
    # bidirectional hold ladder (robot/bench/sweep.py --traj holdbi, read by
    # bench/hysteresis.py) puts it at 0.25-0.30 across 8/10/12 V.  Zero here
    # would silently restore the defect this term exists to fix, so the measured
    # value is the default and `fitted` still says whether a fit has run.
    mu_load: float = 0.28
    # --- inner loop (registers 21/22, 26/27, 24) --------------------------
    kp: float = 32.0          # duty per rad of error, after the register scaling
    kd: float = 0.0           # duty per rad/s
    deadband: float = 2 * ENC_STEP_RAD    # CW/CCW dead zone registers
    punch: float = 0.0        # minimum startup duty once outside the dead zone
    duty_max: float = 1.0
    loop_hz: float = 1000.0   # the servo's own loop rate
    # --- the firmware's goal profile ---------------------------------------
    # The position loop does not chase the target; it chases an internal goal
    # the firmware moves toward the target under a speed cap and an
    # ACCELERATION cap, with ACCELERATION = 0 in the register.  MEASURED
    # (robot/bench/data/{step,chirp}_*.csv, bench/chirp_gain.py, 2026-09-14):
    # a step's peak speed is 2.8*sqrt(step) — 1.1 rad/s for 5.6 deg, 2.5 for
    # 46 — which is the triangle sqrt(a*d) at a = 8, the same on a 0.021 and a
    # 0.028 kg*m^2 arm and at 8, 10 and 12 V, so it is a profile and not the
    # torque; and a = 8 in simulate() reproduces the six chirp curves to 0.2
    # in log gain where 18 misses by 0.5. The speed plateau is the 3.86 above.
    # This one number is the whole of the servo's frequency response: a
    # +-15 deg sine passes 74 % at 1 Hz, 25 % at 2 Hz and 7 % at 5 Hz, while
    # the P loop alone (the law without the profile) passed 100 % at 2 Hz —
    # which is how a policy learned a 5 Hz trot the servos turned into a
    # 0.74 s rocking on the floor.  `profile_goal()`; a state per joint.
    # It is a FIRMWARE CEILING, not a setting (bench/acc_register.py, 2026-09-16,
    # a second servo at 11.6 V): the ACCELERATION register works, in the
    # documented 100 counts/s^2 (ACC 10 -> 1.6 rad/s^2, 49 -> 7.4), but the
    # firmware clamps every write above 50 to 50 = 7.67 rad/s^2, and 0 selects
    # that maximum.  There is no register that lifts it — but MODE 2 (open-loop
    # PWM) has no profile at all: a host PD loop at 250 Hz over one servo (kp
    # 9000 duty/rad, kd 150, kff 200) passed 0.99 / 0.97 / 0.95 / 0.62 of a
    # +-15 deg sine at 1 / 2 / 3 / 5 Hz against the firmware's 0.74 / 0.25 / - /
    # 0.07, the 5 Hz figure being the motor's speed ceiling (bench/pwm_loop.py).
    # The path past this cap is the position loop on the Pi, not a register;
    # the firmware's overload protection is off in that mode (mode2_protect.py).
    goal_acc: float = 8.0     # rad/s^2, the profile's acceleration cap
    goal_vel: float = 3.86    # rad/s, the profile's speed cap (the measured plateau)
    # --- the host loop: MODE 2, the position loop on the Pi ------------------
    # ideas/TRAIN_HOST_LOOP.md.  The servo runs open-loop PWM and
    # robot/runtime/mode2.py closes the loop once per bus round trip, so the
    # firmware's registers above (dead zone, punch, the goal profile) are GONE
    # and what a joint sees instead is
    #     duty = (host_volt_ref / U) * (kp*(target - q) - kd*w),  clipped,
    # recomputed at host_hz (165 Hz measured on the Pi with twelve servos: one
    # SyncRead + one SyncWrite, 6.1 ms) and HELD between, then folded on the
    # servo's current register because the firmware still cuts torque at 2 A
    # for 2 s in MODE 2: full duty at or below fold_i_soft, linearly down to
    # fold_floor of it at fold_i_hard, per servo, and the same fold on the sum
    # over twelve between fold_i_sum*soft/hard and fold_i_sum.  The register is
    # the SUPPLY current, |duty|*|i_motor|, read one sub-tick late.  The
    # thresholds are the runtime's constants, copied, not fitted.  `kp` in this
    # mode is the Pi's number: 5220 duty per rad = 5.22 here.
    host_loop: bool = False
    host_hz: float = 165.0
    host_volt_ref: float = 11.3
    fold_i_soft: float = 1.4
    fold_i_hard: float = 2.0
    fold_floor: float = 0.25
    fold_i_sum: float = 10.0
    # --- transmission -----------------------------------------------------
    theta_bl: float = math.radians(0.5)   # total backlash, rad at the output
    k_bl: float = 3000.0      # N*m/rad once engaged; stiff, not identified
    c_bl: float = 1.0         # N*m*s/rad, engaged damping; numerical, not physics
    enc_after_backlash: bool = True
    # --- numerics ---------------------------------------------------------
    v_eps: float = 0.02       # rad/s, tanh width standing in for sign(); a
    #                           numerical device, never a physical parameter
    # --- provenance -------------------------------------------------------
    fitted: bool = False
    source: str = "vendor spec (2.94 N*m, 4.71 rad/s, 2.7 A stall, all @ 12 V); NOT fitted"
    servo_ids: tuple = ()
    rms_pos_deg: float = float("nan")
    rms_current_a: float = float("nan")

    # -- derived, for reporting -------------------------------------------
    @property
    def k_w(self) -> float:
        """Back-EMF torque coefficient, N*m*s/rad. Not free: k_u * k_e."""
        return self.k_u * self.k_e

    def stall_torque(self, u_bat: float) -> float:
        return self.k_u * u_bat

    def no_load_speed(self, u_bat: float) -> float:
        return u_bat / self.k_e

    def to_json(self, path: str) -> None:
        d = dataclasses.asdict(self)
        d["servo_ids"] = list(self.servo_ids)
        d["_derived"] = {
            "k_w_Nm_s_per_rad": self.k_w,
            "stall_Nm_at_12V": self.stall_torque(12.0),
            "stall_Nm_at_9.9V": self.stall_torque(9.9),
            "no_load_rad_s_at_12V": self.no_load_speed(12.0),
            "backlash_deg": math.degrees(self.theta_bl),
        }
        os.makedirs(os.path.dirname(os.path.abspath(path)), exist_ok=True)
        with open(path, "w") as f:
            json.dump(d, f, indent=2)

    @classmethod
    def from_dict(cls, d: dict) -> "Params":
        d = {k: v for k, v in d.items() if not k.startswith("_")}
        if "servo_ids" in d:
            d["servo_ids"] = tuple(d["servo_ids"])
        known = {f.name for f in dataclasses.fields(cls)}
        return cls(**{k: v for k, v in d.items() if k in known})


# A Params of scalars is a container of Python floats; a Params whose fields are
# arrays is a batch of servos. The second only survives a jax transform if jax
# knows which fields are data and which are provenance — without this, `vmap`
# over a Params is a silent no-op that hands every environment the SAME servo,
# and domain randomisation looks like it is working while doing nothing.
#
# Registered behind a try/except on purpose: the mac's check runs and the Orange
# Pi import this file with no jax installed (rl/CLAUDE.md), and that has to keep
# working. source/servo_ids/fitted are str/tuple/bool and cannot be traced;
# rms_* are how well a fit went, not state.
try:
    import jax as _jax

    _jax.tree_util.register_dataclass(
        Params,
        data_fields=["R", "k_e", "k_u", "J_m", "J_l", "tau_c", "b_v", "mu_load",
                     "kp", "kd", "deadband", "punch", "duty_max", "loop_hz",
                     "goal_acc", "goal_vel", "theta_bl", "k_bl", "c_bl", "v_eps",
                     "host_hz", "host_volt_ref", "fold_i_soft", "fold_i_hard",
                     "fold_floor", "fold_i_sum"],
        # host_loop is a mode, not a draw: Python control flow in the functions
        # below, so it has to stay a static bool through a jit
        meta_fields=["enc_after_backlash", "host_loop", "fitted", "source",
                     "servo_ids", "rms_pos_deg", "rms_current_a"])
except ImportError:                       # numpy-only machine; nothing to register
    pass


DEFAULT_PATH = os.path.join(os.path.dirname(os.path.abspath(__file__)),
                            "params", "st3215.json")


def load(path: str = DEFAULT_PATH, quiet: bool = False) -> Params:
    with open(path) as f:
        p = Params.from_dict(json.load(f))
    if not p.fitted and not quiet:
        print(f"!! {os.path.relpath(path)} is NOT a fit: {p.source}\n"
              f"!! Training against this trains against the datasheet. Run\n"
              f"!! robot/bench/sweep.py and robot/bench/fit_bam.py first.")
    return p


# ======================================================================= law
def _sign(w, v_eps, xp=np):
    """tanh in place of sign(): least_squares needs a derivative, and a true
    sign() makes the Coulomb term a wall the optimiser cannot see across."""
    return xp.tanh(w / v_eps)


def duty(p: Params, err: float, w: float, xp=np, u_bat=None) -> float:
    """The position loop, on a quantised error, in [-duty_max, duty_max].

    Firmware mode: the servo's own loop.  The dead zone and the punch are real
    registers (26/27 and 24) and they are what makes a bus servo buzz around its
    target instead of settling: inside the dead zone there is no drive at all,
    and the first drive outside it is not infinitesimal but `punch`.

    Host mode (`p.host_loop`): the Pi's loop, robot/runtime/mode2.py `_pd`.  No
    dead zone, no punch; the PD on the encoder count, scaled by
    host_volt_ref / u_bat so the stiffness in VOLTS is constant as the pack
    drains (the sim's U = duty*U_bat then makes it voltage-independent until the
    duty clips).  `u_bat` is required there and ignored otherwise.
    """
    # NOTE: round() has zero gradient almost everywhere. PPO never
    # differentiates through the sim so this costs nothing here, but it does
    # make this law unusable for anything that wants dynamics gradients.
    e = xp.round(err / ENC_STEP_RAD) * ENC_STEP_RAD          # the encoder's view
    if p.host_loop:
        if u_bat is None:
            raise ValueError("host-loop duty needs u_bat: the Pi scales by 11.3 / U")
        u = (p.kp * e - p.kd * w) * (p.host_volt_ref / u_bat)
        return xp.clip(u, -p.duty_max, p.duty_max)
    e = xp.where(xp.abs(e) <= p.deadband, 0.0, e)
    u = p.kp * e - p.kd * w
    u = xp.where((u != 0.0) & (xp.abs(u) < p.punch), xp.sign(u) * p.punch, u)
    return xp.clip(u, -p.duty_max, p.duty_max)


def current(p: Params, u_volt: float, w: float, driven=True, xp=np) -> float:
    """Motor current, A. i = (U - back-EMF) / R — the channel that separates the
    electrical damping from the mechanical, and the only reason the fit closes.

    `driven=False` is Torque Enable = 0: the bridge is off, the winding is open,
    and there is no current at all whatever the shaft is doing.
    """
    return xp.where(driven, (u_volt - p.k_e * w) / p.R, 0.0)


def friction(p: Params, w: float, tau_t: float, xp=np,
             tau_c_external: bool = False) -> float:
    """Gearbox friction: a constant, a term that grows with LOAD, and a viscous one.

    The middle term is the one most models leave out, and leaving it out is not a
    small approximation on a 1:345 spur stack. Gear-tooth friction is proportional
    to the normal force between teeth, which is proportional to the torque being
    transmitted, so friction is not a property of the gearbox alone — it is a
    property of the gearbox and its present load. Measured on this servo
    (robot/bench/sweep.py --traj holdbi, three voltages): 0.19 N*m at no load,
    growing by 0.28 N*m per N*m carried, so at the 0.88 N*m the bench arm asks
    for, friction is 0.41 N*m — half the load again.

    Until this term existed the fit had nowhere to put that and put it in `k_u`,
    which is why the identified stall was 4.23 N*m against a spec 2.94, and why
    `b_v` sat pinned on its lower bound however much data it was given.

    **There is deliberately no forward/back-driving asymmetry here**, and that is
    a conclusion rather than an omission. The bench reports ~28 % of motor torque
    lost forward-driving against ~62 % back-driving, which reads as a strongly
    asymmetric gearbox — but almost all of that gap is `tau_c` being a FIXED
    offset measured against two very different load levels. Run the symmetric law
    above at each: forward, 0.19 + 0.28*0.88 = 0.41 N*m out of the 1.29 the motor
    supplies, i.e. 32 %; back-driving over a free swing's mean gravity torque,
    56 %. Both land on the reported numbers without a second coefficient, and a
    second coefficient fitted to the residual of the first would not be
    identifiable from this bench anyway.

    **`tau_c_external` says who applies the Coulomb floor, not whether it
    exists.** `_sign()` is `tanh(w/v_eps)`, which is exactly zero at rest, so
    this expression cannot hold a joint at w = 0 — the defect PLAN.md 2b names.
    `simulate()` below fixes it with Karnopp, because it has every torque as
    state and can ask whether the NET one is below breakaway. The MuJoCo
    consumers — `rl/env/walk.py`, `rl/eval.py`, `rl/tools/` — cannot: MuJoCo owns
    the load, so at the moment this is called the net torque does not exist yet.
    There the floor is MuJoCo's own `dof_frictionloss`, a real stick-slip
    constraint solved with everything else, installed by `model.build_spec()`;
    those callers pass `tau_c_external=True` and the floor is applied once rather
    than twice. What stays here on that path is deliberate: `frictionloss` is one
    constant per joint and cannot carry `mu_load*|tau_t|` — roughly 0.11 N*m of
    the ~0.30 at stance — and viscous drag does not stick, so `b_v*w` was never a
    candidate for it either.
    """
    tau_c = 0.0 if tau_c_external else p.tau_c
    return ((tau_c + p.mu_load * xp.abs(tau_t)) * _sign(w, p.v_eps, xp)
            + p.b_v * w)
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

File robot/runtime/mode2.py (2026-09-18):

"""
mode2.py — the runtime with the position loop on the host: MODE 2 (open-loop PWM).

    python runtime/mode2.py --selftest                         # no hardware
    python runtime/mode2.py --port /dev/ttyACM0 --id 1 --sine  # one free servo, a bench check

Why
---
The ST3215's own position loop profiles every goal at a firmware-capped 7.7 rad/s²
(`ideas/FAST_SERVOS.md`): a ±15° sine gets through at 74 % at 1 Hz and 7 % at 5 Hz,
and every RL policy that asked for a 5 Hz trot rocked in place. MODE 2 drives the
bridge at a duty with no profile, and a PD on the host — measured on one servo at
250 Hz — passes the same sine at 99 / 97 / 95 % at 1 / 2 / 3 Hz.

`Mode2Runtime` is `loop.Runtime` with the servo's loop replaced by ours. The 50 Hz
tick is unchanged — read, guard, source, send — and the source still hands over
joint angles. What changes is that `send` does not write a goal: it stores the
target, and the time the base loop would have SLEPT until the next tick is spent
running the PD as fast as the bus goes:

    duty = kp·(target − q) − kd·ω + kff·ω_target        (joint frame, then the servo's)

with the gains from `bench/pwm_loop.py`'s tuned run and scaled by 11.3 V / pack
volts so the stiffness (≈ 41 N·m/rad, the firmware's own) does not drift with the
pack.

Three things the firmware did for us that we now do ourselves
-------------------------------------------------------------
**The centre.** `PRESENT_POSITION` is raw in MODE 2 — `OFFSET` (the servo's own
middle-position calibration) is not applied, so `calib.json`'s centres, taken in
position mode, are off by exactly that. The switch measures it: read counts in
MODE 0, switch, read again, shift the centre by the difference. The position is
then decoded through the 0/4095 wrap, because a raw centre can sit anywhere.

**Current.** The firmware still cuts torque at `PROTECTION_CURRENT` (2 A) after
`OVERCURRENT_TIME` (2 s) in MODE 2 — measured stalled, `bench/mode2_protect.py`
— and a servo cut that way is dead until torque is cycled: a leg going limp
mid-stride. So the duty is folded back on the register current before the
firmware can act: full duty below `i_soft`, down to `i_floor` of it at `i_hard`,
per servo, and the same fold on the whole bus against `i_sum`, which is what
stops twelve joints pulling stall current together off one pack. `safety.Guard`
still trips at its own `current_a` for `current_hold_s`; the fold is what keeps
it from having to.

**Runaway.** The loop closes in the encoder's frame, so a sign wrong in
`calib.json` moves a joint the wrong way but still tracks — the same fault it is
in position mode. What does run away is a servo whose bridge turns the count the
other way from the one measured (+duty, count down: one unit, one firmware), or
a joint driven off its target by a jam. Positive feedback at 9000 duty/rad hits
full duty in a few counts, and the guard's tracking check needs 0.3 s — 1.4 rad
of leg at 4.7 rad/s. So the host loop has its own: an error past `runaway_rad`
on any sub-tick zeroes every duty and trips at once.

**A torque ceiling.** In position mode the firmware never let a joint hold full
duty: `OVERLOAD_TORQUE` 80 cut anything above 80 % to 20 % after 2 s, and
`PROTECTION_CURRENT` bounded a held stall to ~2.3 N·m. In MODE 2 both are ours to
provide, and the fold above only sees a stall once the current register has
climbed. `duty_cap` is the per-joint ceiling that stands in for them: a joint
capped at 600 gets 7 V of drive at the pack's 12 V, which the torque rig read as
2.3 N·m — the firmware's own sustained bound — against ~3.3 N·m at full duty on a
fresh pack. It exists because the front hip brackets broke under the pitch
servos' full duty on the first day the feet gripped (siped soles, 2026-09-17):
`3d/fea.py`'s `stall` case reads SF 2.2 for `hip_bracket_A` at 3.2 N·m, and a
hop's landing is on top of that. The cost is speed: no-load speed scales with
drive, so a capped joint is slower than the 4.7 rad/s ceiling the gait is fitted
to. Which joints, and how much, is **verify** — `--duty-cap pitch=600` on
`walk.py` / `policy.py`, `duty_cap:=` on `robot.launch.py`.

MODE is EEPROM and `cut()` puts 0 back, duty 0 and torque off first. A process
killed with SIGKILL cannot: the servos keep their last duty until power is cycled
or the next run's preflight finds MODE 2 and restores it.
"""
from __future__ import annotations

import argparse
import collections
import math
import os
import sys
import time

HERE = os.path.dirname(os.path.abspath(__file__))
sys.path.insert(0, os.path.dirname(HERE))

from feetech import registers as R                                   # noqa: E402
from feetech.bus import Bus, BusError, Servo                         # noqa: E402
from feetech.loopback import LoopbackBus                             # noqa: E402
from runtime.calib import Calibration                                # noqa: E402
from runtime.loop import CTRL_HZ, Runtime                            # noqa: E402
from runtime.safety import Limits, Tripped                           # noqa: E402

#: Measured on one servo at 11.3 V, 250 Hz, `bench/pwm_loop.py --kp 9000 --kd 150
#: --kff 200`: 0.99 / 0.97 / 0.95 / 0.62 of a ±15° sine at 1 / 2 / 3 / 5 Hz.
KP, KD, KFF = 9000.0, 150.0, 200.0
VOLT_REF = 11.3
DUTY_MAX = 1000


def parse_duty_caps(spec, joints) -> dict:
    """`"pitch=600,fl_roll=800"` -> {joint: cap}. A key is a joint name or a joint
    kind (`roll`, `pitch`, `knee`: every joint whose name ends in it); an empty
    spec is no caps. Unknown keys and caps outside 1..DUTY_MAX are errors, not
    silence — a typo here is a bracket."""
    caps = {}
    for item in (spec or "").replace(";", ",").split(","):
        item = item.strip()
        if not item:
            continue
        if "=" not in item:
            raise ValueError(f"duty cap {item!r}: want NAME=DUTY")
        key, val = (x.strip() for x in item.split("=", 1))
        cap = int(val)
        if not 1 <= cap <= DUTY_MAX:
            raise ValueError(f"duty cap {item!r}: {cap} is outside 1..{DUTY_MAX}")
        hit = [n for n in joints if n == key or n.endswith("_" + key)]
        if not hit:
            raise ValueError(f"duty cap {item!r}: no joint called or ending in {key!r}")
        for n in hit:
            caps[n] = min(cap, caps.get(n, DUTY_MAX))
    return caps


def duty_word(d: int) -> int:
    """Register 44 in MODE 2: magnitude in the low bits, direction in bit 10."""
    d = int(max(-DUTY_MAX, min(DUTY_MAX, d)))
    return abs(d) | (0x400 if d < 0 else 0)
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

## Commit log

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2026-08-29 ros2: publish the IMU, drive from the sim window, add a terrain world and a viewer
    The gait had no sensor to close a loop on: nothing spawned imu_sensor_broadcaster
    and the URDF declared no IMU, so the walker ran blind. The xacro now declares
    "imu_imu" (prefix + kind — mujoco_ros2_control keys off that name) and the launch
    spawns the broadcaster after the joint-state one; `imu:=false` skips it, and
    everything else still comes up if that controller is not installed.
    Teleop stops needing an xterm: mujoco_ros2_control republishes keys pressed over
    its viewer on ~/key, so the keyboard node runs inside the launch and takes them
    from the window. Running it by hand still works, on a TTY — but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
    [smalldog-controllers.yaml, smalldog-mujoco.urdf.xacro]
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2026-08-29 Put the thigh's cable-tie slots back to sharp rectangles
    Rounding them was the obvious "corners concentrate stress" move, and measured
    it buys nothing: thigh_A stall at 1.2 mm reads 23.19 MPa sharp, 23.15 obround,
    22.95 obround stopping short of the pocket wall, 22.98 with no slot at all.
    The slot is worth 0.2 MPa of 23. The 2.0 mm arm spreads 15.7..18.5 over the
    same four, which is one mesh's luck on an unconverged corner and must not be
    read as a result either way.
    The peak is somewhere else entirely: the knee sleeve's cable window leaves this
    beam's two +-y walls unsupported over the 15 mm it spans, and both hot cells
    sit 0.3 mm inside its edges. Bounding that window in local z is the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
    [fl_thigh.stl, fr_thigh.stl, rl_thigh.stl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]
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2026-08-29 robot,rl: the ST3215 as a voltage law, plus the bench that measures it
    Step 3. rl/actuator.py replaces the ideal PD with the chain the robot actually
    has: an inner loop on a quantised encoder with the servo's own dead zone and
    punch registers, a duty that multiplies the SUPPLY voltage, back-EMF, Coulomb
    and viscous friction, and a deadzone spring for the gearbox play. robot/ is the
    hardware side that feeds it: a half-duplex SMS/STS driver, a trajectory runner,
    and a fitter.
    Three things in the physics were found by testing rather than by writing:
    * Torque Enable = 0 opens the winding, it does not brake. Modelled as a brake,
    the free-swing run reads k_w = k_u*k_e = 0.62 N*m*s/rad as m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
    [actuator.py, bus.py, bus_probe.py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]
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2026-08-31 sim: one copy of the MuJoCo joint feel, not two that disagree
    rl/checks/check_model.py on the WSL2 box reported the two exporters
    declaring different actuators for the same servo:
    3d/export_sim.py damping 0.5 armature 0.01 frictionloss 0.05 kp 20
    ros2/.../generate_model.py damping 0.12 armature 0.008 frictionloss 0.02 kp 25
    Both files import mini_dog and both kept their own literals, which is the
    servo-mass failure this repo already records (55 g in the CAD, 60 g in
    the ROS 2 model, 60 g of robot) repeated one section down. export_sim.py
    also carried no dampratio at all, so its kp was not a different tuning of
    the same actuator, it was a different actuator: an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
    [mini_dog.py]
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2026-08-31 rl: the servo law goes under jax, and the sag gets a floor
    train_ppo.py needs actuator.py inside a vmapped, jitted rollout and the file
    was written for numpy on a bench. Three changes, none of which alter what the
    law computes on the mac.
    `Params` is registered as a jax pytree dataclass. Without it, a Params whose
    fields are arrays is not a batch of servos: jax treats the whole dataclass as
    one leaf, `vmap` over it is a silent no-op, and every environment is handed the
    SAME servo while domain randomisation appears to be working. That failure is
    quiet and it invalidates a whole run, which is why the registration lives next
    to the dataclass rather than in the env that happens to need it.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
    [actuator.py]
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2026-08-31 cad: the foot bolt gets a hole that reaches the outside
    foot() cut its M3 clearance hole from zf-6 and its head pocket from
    zf-1, both written as if the dome's radius were 6 rather than
    FOOT_D/2 = 13. The hole therefore opened 7 mm INSIDE the solid and
    never broke the sole at all, and the pocket's one annulus - at zf-1,
    between r 1.7 and 3.4 - faced up, while the nut above pulls the bolt
    up and the head needs a face looking down. So step 4 of README's
    assembly order was not merely awkward, it was impossible: there was
    no path in and nothing to bear on.
    The bolt was specified as M3 x 16. The span from the sole to the
    nut's far face is 28 mm, so no position of the head could ever have
    reac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
    [fl_shin.stl, fr_shin.stl, rl_shin.stl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]
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2026-09-02 runtime: the 50 Hz loop, and the controller it does not know about
    Step 7. `robot/runtime/` was the last empty row in robot/README.md and it is
    the whole gap between a policy that walks in MuJoCo and a robot that walks on
    the floor.
    `loop.Runtime` takes `source(dt, feedback) -> 12 joint angles` and owns
    everything around it: the SyncWrite/SyncRead pair, the timing, the clamp and
    the torque. It does not know what a trot is, so the analytic gait (today) and
    the ONNX policy out of rl/ (step 6) share one safety layer and one calibration
    instead of each growing their own.
    The tick is read -> guard -> source -> write. Writing first has less jitter on
    the actuation and costs a tick of freshness;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
    [calib.py, loop.py, safety.py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]
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2026-09-03 cad: the clamp screw is inside the fork's sweep, and no check could see it
    The first assembled leg binds on its own thrust clamp. Every printed solid in
    this file passes — isValid, interference(), rom_scan over all three joints — and
    the leg still will not move, because the part sticking out is a screw and no
    screw was in the model.
    The lug was never the problem: its corner is at 21.57 against the SPINE_R0 = 23
    the distal fork sweeps, and that is the 21.6 the README has always quoted. The
    screw is. The bolt is a jack, so its tip ends on the case with the case pushed
    fully forward, x = -9.76, which leaves an M3x10 bearing face 0.65 proud of the
    lug. Put a DIN 912 cap head on that and its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
    [mini_dog.py]
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2026-09-03 cad: the roll joint's inboard fork screws cannot be reached, and now that is checked
    Reported off the bench: one side of the bracket has no access to its bolts. It
    is not awkwardness, it is 0.6 mm. The passive-hub arm's outer face sits at
    x = 68.1 and roll_module's root gusset ends at 67.5; behind that is 2.8 mm of
    solid wall and then the gusset's hollow. Four screws per hip_bracket, four legs,
    and no driver that can turn any of them.
    There is also no assembly order that avoids it. The fork's arms straddle the
    sleeve — they sit at x 68.1..72.1 and 110.3..114.3 against a sleeve spanning
    73.5..106.5 — so the fork goes on radially, over a servo that is already in its
    bore, and the screws a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
    [mini_dog.py]
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2026-09-03 docs: MAC.md, the queue of CAD that has never met CadQuery
    Five commits changed 3d/ from a session that had none, two of them moving
    printed geometry, and the machine that can actually run any of it is the mac.
    WSL.md is a permanent runbook for its box; this is deliberately not that. It is
    a queue, and it says to delete sections as they come back green.
    Written around the ladder in 3d/CLAUDE.md rather than beside it, because the
    order is the part that is easy to get wrong. Step 0 is the one that would
    otherwise be missed: fea.py is a comparison and the "before" is already
    committed, so the baseline has to come out of a git worktree at b4d7e4a - the
    last commit whose mini_dog.py is the old o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
    [mini_dog.py]
2026-09-03 cad: the access bores inverted the chassis, and isValid() said it was fine
    Working the MAC.md queue: five commits had changed 3d/ from a session with no
    CadQuery, so none of it had been through a boolean. Step 1 came back with
    chassis_bottom at -0.3 cm3.
    7e30e75 cut its four @6 bores BEFORE the rear connector pads were unioned on,
    and the pads start at exactly the plane the bores end on - xw+WALL = -60.2
    against the bores' BODY_L/2-WALL = 60.2. They share no volume at all; the pad's
    inner face was welded straight onto the bore's circular opening, and OCC's fuse
    on that degenerate contact returned an INVERTED solid. isValid() said True, so
    nothing downstream noticed: 240 cm3 of chassis be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
    [base_link.stl, fl_hip.stl, fl_shin.stl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]
2026-09-04 cad: the hip's inboard fork screws are reached through the corner, and the leg turns
    The four coaxial bores of 7e30e75 reached one screw of four (MAC.md, 2026-09-03):
    a deck boss stood in front of two, the outboard one ran 0.2 mm inside the side wall,
    and a coaxial bore only lets a key tilt 12 deg. No path into the tray can work - the
    battery cradle's end stop closes every one within 18 mm.
    Replaced by fork_access_channels(): two @6 channels per hip, on the "out" and "top"
    positions of the hub circle, leaning KEY_TILT = 20 deg outboard, cut last on the
    assembled chassis. In open air past the tray's front corner after 8 mm and 29 mm
    (the second passes under the corner deck boss's screw hole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
    [base_link.stl, robot.xml, smalldog.urdf]
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2026-09-07 runtime: the servo ids are <leg><joint>, and the bus scan stopped at 20
    The ids are the builder's, not the model's, so they are chosen once and written
    down: the first digit counts the legs round the robot from the front right (1)
    to the front left (2), rear left (3), rear right (4), the second counts a leg's
    servos from the body (1 = roll) to the ground (3 = knee). 11-13, 21-23, 31-33,
    41-43, and id 32 is the rear-left pitch without looking anything up.
    The leg digit does NOT follow robot_params.json's fl, fr, rl, rr order, which is
    why LEG_DIGIT is a written-down table rather than an enumerate(): there is
    nothing to derive it from, and deriving it would silently swap the two front
    legs. T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
    [bus.py, bus_probe.py, calib.py]
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2026-09-07 runtime: the servo's temperature byte is noise while it drives, and it tripped the first stand
    The first --stand on real hardware tripped: `over temperature on fl_pitch: 65.00`,
    on a servo a direct read showed at 30 C a second later. It was not the servo and
    not the bus.
    PRESENT_TEMPERATURE is clean to +-1 C while a servo is still — thousands of
    samples on a stationary ST3215, not one outlier — and unreliable the moment its
    motor drives. The same servo at a true 30 C returned isolated bytes of 41, 48,
    54, 56 and 98, and a raw maximum of 150 C over the 21 s trot. It happens on both
    the SyncRead and the single-read path, and the voltage byte beside it is correct
    in every frame, which is w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
    [loop.py, safety.py]
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2026-09-08 runtime: the gait is fitted to the servo, and the robot got twice as fast by slowing down
    The 0.20 m/s trot does not walk at 0.20 m/s. gait.py rate-limits its own output to
    joint_velocity_limit * 0.85 = 4.0 rad/s and that gait demands 7.55 - 89 % over - so
    the commanded foot path is clipped before a servo ever sees it. Measured at 2.55 kg:
    0.067 m/s achieved, 0.86 A peaks, and the knee-load residual peaking in the half the
    gait calls SWING on all four legs in two independent runs, which is a foot that never
    leaves the ground. --period cannot help: period_for() pins the period at 0.45 s at
    that speed whatever is passed.
    feasible_gait() picks the shortest period whose demand fits under the li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
    [safety.py, walk.py]
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2026-09-08 sim: a planted foot was a frictionless pivot, and the patch that fixes it changes nothing
    The foot's contact constants were the same defect a fifth time: MJ_FOOT_*
    existed in both exporters and had diverged (torsion 0.05 here against 0.02 in
    the ROS 2 generator) while BOTH shipped MuJoCo's default condim="3", which
    reads only the first friction column. So the torsion number was in two files,
    different in each, and used by neither - a foot on the ground resisted no twist
    at all. They now live once in mini_dog.py section 4 and both exporters read
    them.
    condim is 4, not 6. The rolling dimension takes the terrain sweep from
    657 +-35 mm to 615 +-124 - the mean moves less than the spread but t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
    [defaults.xml, robot.xml]
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2026-09-08 bench: PRESENT_CURRENT is supply current, not motor current, and that is d^2 U/R
    Holding 0.865 N*m the servo reported 0.084 A - an order of magnitude below the
    ~0.5 A a motor making that torque must carry - and the fit's torque-vs-current
    line had an unphysical +0.118 N*m intercept. It is not the sensor. A PWM'd
    brushed motor at duty d sits at I_motor = d*U/R, and the supply behind the
    bridge sees only d of that, so the register reads d^2 * U / R.
    Inverting that over the hold ladder, with d from PRESENT_LOAD across a 7x range
    of duty, gives R = 4.29, 4.29, 4.29, 4.44, 4.36, 4.33 ohm - six points inside
    3 % of the 4.44 the vendor's locked-rotor spec implies, a number this register
    was neve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
    [actuator.py, fit_bam.py, registers.py]
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2026-09-09 bench: friction measured instead of fitted, and the raw logs now travel
    PLAN.md step 1. Two trajectories in sweep.py, both differential: `holdbi`
    walks the hold ladder up and then down so every angle is reached from both
    sides, and `speed` is the same triangle at five periods from 20 s to 1 s.
    Captured at 8/10/12 V on the 1.066 kg / 90 mm arm; bench/hysteresis.py reads
    The fit was never going to find friction. actuator.py's law is
    tau_c*sign(w) + b_v*w, both independent of load, so friction that grows with
    the torque carried has nowhere to go except k_u — hence a fitted stall of
    4.23 N*m against a spec 2.94, and a b_v pinned on its bound however much data
    it is given. So measure it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
    [chirp_m0.43_r0.09_v10_225801.csv, chirp_m0.43_r0.09_v12_225202.csv, chirp_m0.43_r0.09_v8_230140.csv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]
2026-09-09 actuator: friction that grows with load, and two things it did not fix
    PLAN.md step 2. `Params.mu_load` is N*m of friction per N*m crossing the
    gearbox, applied in actuator.friction() and in simulate()'s integrator, which
    now computes the transmitted torque BEFORE the motor torque because the latter
    depends on it. Callers that do not own a transmission - rl/env/walk.py and
    rl/eval.py, where MuJoCo does - get a proxy whose conversion is exact for
    forward driving at steady state, and the docstring says where it is not.
    fit_bam.seed_from_holdbi measures it off the bidirectional ladder and runs
    FIRST, because it needs nothing and the free swing needs it: that pass gets J_m
    from (m*g*r*sin q0 -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
    [actuator.py, fit_bam.py]
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2026-09-09 bench: a dry run writes a real csv, and the fit was going to eat it
    sweep.py --dry-run produces a file with the real name, the real columns and the
    real --out directory; the only thing marking it is "dry_run": true in the header
    that fit_bam.py never read. Checking the rig before a bench session is the
    correct thing to do, so those files WILL exist, and the failure mode is silent:
    the ST3215 gets identified partly against a simulation of itself, and nothing in
    the output says so. check_identifiable already guards the voltage spread, the
    current, the free swing and the register set — this was the hole beside them.
    Two layers, because the data is expensive and the operator is holding a
    sold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
    [fit_bam.py, sweep.py]
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2026-09-09 cad: the hip-roll cradles bolt on, and the rear panel opened into solid plastic
    Carries TWO changes rather than one, and that is deliberate: they are interleaved in the
    same files, and the generated ROS 2 description cannot be split between them without
    leaving one commit's model stale against its own CAD - which 3d/CLAUDE.md forbids
    outright. Both ladders are in MAC.md.
    1. THE BATTERY BECAME A MODULE (worked earlier the same day). Six 21700 welded into a
    3 x 2 brick, heatshrunk, the BMS beside them, all of it in battery_case + battery_lid
    dropping into a seat recess as one payload. The cradle's fins, end stops and front
    BMS bay are gone. The binding constraint was height and i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
    [base_link.stl, robot.xml, smalldog.urdf]
2026-09-09 sim: the fitted actuator, and the old model let the legs turn 13x too fast
    PLAN.md step 3. Four constants in mini_dog.py section 4, all four replaced by
    measurements off a real ST3215 at three supply voltages. The block used to open
    "NOT measured ... plausible values"; it now carries provenance instead.
    MJ_KP 25.0 -> 40.9 N*m/rad friction-cancelled stiffness at 12 V
    MJ_FRICTIONLOSS 0.02 -> 0.184 N*m Coulomb, two routes agreeing
    MJ_DAMPING 0.12 -> 1.37 N*m*s/rad the TOTAL speed-proportional torque
    MJ_ARMATURE 0.008 -> 0.0165 kg*m2 free swing at the corrected tau_c
    Two are not the parameter the plan named. MJ_KP moved because the stiffness was
    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
    [defaults.xml]
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2026-09-09 bench: the scale is 28 mm, and the clearance check was flattering it
    SCALE_H measured on the instrument actually in use, replacing a 45 mm design
    assumption. It is read only by throat_clear(), so no geometry moves and the
    already-sliced plate stands - both parts come out at 216.1 and 84.3 cm3, the
    same as what went into out/gcode/torque_rig.3mf.
    The check itself was wrong, and in the direction that hides a problem. It
    reported the gap from the scale's platform up to the AXIS as room for the anvil
    screw, but the arm is in the way: it is ARM_TIP_W thick about the axis, so the
    screw only bridges from the arm's UNDERSIDE down. At the 45 mm assumption that
    was the difference between a claimed 15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
    [torque_rig.py]
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2026-09-09 cad: the BMS is 60.13 x 37.2 x 5.9, and that cost the case its y retention
    The last **verify** row on the battery module met the real board. All three
    catalogue numbers were wrong: 64 x 27 x 13 guessed against 60.13 x 37.2 x 5.9
    measured, the thickness over the heatsink plate. The orientation is forced by
    the case - a 60.13 mm edge cannot stand up in a 43.6 mm interior.
    The thickness is 7.1 mm under the guess and comes straight off BATT_IN_L, so
    the module went 102.3 x 68.2 x 46.4 -> 95.2 x 68.1 x 46.4 and the robot lost
    about 2 g. BATT_X is deliberately not re-centred: holding it walks the heavy
    brick 3.55 mm aft, the direction the module owed the CoM when the BMS went in
    behind the cel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
    [base_link.stl, robot.xml, smalldog.urdf]
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2026-09-10 cad: two printed combs hold the cells on a pitch, and the module grows by the gaps alone
    `cell_holder`, x2, one at each end of the cells. It exists because welding six
    loose cylinders into a 3 x 2 brick by hand is the assembly step this design had
    no answer for - the combs turn the six into one riggable object before any
    nickel goes on.
    The obvious holder is a frame round the outside of the array and it does not
    fit: the module already has 1.4 mm to the deck and 0.5 mm to the deck screws'
    nut bosses at |y| = 35.2. So the caps are clipped flush with the outermost
    cells' own tangent planes in both y and z - no material outboard of any cell
    anywhere - and the module grows by the separator ga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
    [base_link.stl, robot.xml, smalldog.urdf]
2026-09-10 bench: the ST3215 makes 4.50 N*m, measured on a scale, not 2.94
    PLAN.md step 2c, closed. A printed C-frame with a 170 mm arm pressing an M6
    anvil onto a 2 kg coffee scale, three duty rungs at 12 V: k_u = 0.400 N*m/V,
    friction intercept -0.30 N*m, stall 4.50 N*m (4.38 read warm), residuals
    +-0.05 N*m.
    BOTH PREVIOUS ANSWERS WERE WRONG, IN OPPOSITE DIRECTIONS. The register routes
    implied 7.40 and the datasheet said 2.94; the truth is between them, so the
    register channel is high by 1.64x - not the 2.2x the old note assumed - and the
    datasheet is optimistic by 1.53x on top of that. There was never one mis-scaling
    to find. The -0.30 N*m intercept is a third independent read on tau_c, against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
    [defaults.xml, smalldog.urdf, stall_m0_r0_v12_204015.csv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]
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2026-09-11 bench: a tool for the no-load speed, the last vendor number in the chain
    SERVO_NOLOAD_RADS = 4.71 has never been checked, and its neighbour
    SERVO_STALL_NM turned out to be wrong by 53 % the moment a scale was put on it.
    It is not decorative any more either: ros2/smalldog_walker/gait.py used to
    derive its slew limit straight from it (that was step 3b), and the ceiling that
    replaced it, (forcerange - frictionloss)/damping, has MJ_DAMPING underneath -
    fitted while assuming this figure.
    Two traps the tool refuses to let you walk into.
    TORQUE_LIMIT caps duty and terminal speed is d*U/k_e, so a capped servo reports
    a capped speed: at the 350 the torque rig leaves behind you would measure
    2.07 ra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
    [noload_speed.py]
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2026-09-11 rl: the training path had no friction at rest, and MuJoCo is where it goes (step 2b)
    `actuator.py`'s Coulomb term is `(tau_c + mu_load*|tau_t|)*tanh(w/v_eps)`, which
    is exactly zero at w = 0. `model.build_spec()` zeroed MuJoCo's `frictionloss` on
    the grounds that the law supplies it — so a standing or stancing robot in `rl/`
    felt NO joint friction at all, while the real servo breaks away at 0.18-0.35 N*m
    and `ros2/` has carried 0.184 since 2026-09-09. At ~0.3-0.5 N*m of knee torque in
    stance that is a third to a half of the load, and step 3 made the gap wider
    rather than narrower: both sims were wrong together at 0.02 before it.
    Karnopp fixed this inside `simulate()` on 2026-09-11 and cou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
    [actuator.py]
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2026-09-11 rl: the episode boundary was not in the env, and five randomisation axes were dead
    A read-only review of rl/ found that brax's AutoResetWrapper restores only
    pipeline_state and obs, and ppo.train calls env.reset once per run - so the
    command, the actuator/pack/bus draw, obs_hist and foot_xy were all sampled
    once and held for 60 M steps. ~15 % of environments stood still forever, the
    per-episode draw was per-environment, each new episode opened on four frames
    of the previous fallen robot, and foot_slip charged a metre of skid that never
    happened on the first step after every reset (boundary slip 85x interior).
    Walk.step now redraws everything an episode owns, gated on the
    info["episode_done"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
    [actuator.py]
2026-09-11 robot: the bench put torque on before the goal, and the lift test ran unguarded
    A read-only review of robot/ found seven safety-relevant defects; all fixed
    and covered by the no-hardware selftests (16 new cases, all trees green).
    - lift_test.py's hand-rolled loop never called guard.update(), so nothing
    checked current, voltage, tracking or bus loss for the 24 s loaded hold.
    It now runs through Runtime.run(), where the guard runs every tick, and a
    trip is caught and reported.
    - sweep.py, torque_hold.py and noload_speed.py enabled torque BEFORE writing
    the goal - the exact hazard loop.engage() documents. Goal first, then torque.
    - noload_speed.py --pwm raised TORQUE_LIMIT to 1000 and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
    [bus.py, calib.py, fit_bam.py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]
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
